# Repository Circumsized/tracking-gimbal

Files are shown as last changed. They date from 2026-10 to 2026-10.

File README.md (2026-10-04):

# 基于树莓派 Zero 2 W 的双轴微型视觉跟踪与测距云台系统









---

## 目录 (Table of Contents)

- [1. 系统全景与工程架构](#1-系统全景与工程架构)
  - [1.1 总体架构与数据流拓扑图 (SVG 矢量全景)](#11-总体架构与数据流拓扑图-svg-矢量全景)
  - [1.2 云台机械结构正交布局与 CAD 装配体系 (SVG 矢量图)](#12-云台机械结构正交布局与-cad-装配体系-svg-矢量图)
  - [1.3 系统物理拓扑与电气互联网络 (Mermaid)](#13-系统物理拓扑与电气互联网络-mermaid)
  - [1.4 树莓派 40-Pin GPIO 物理引脚工程映射 (ASCII)](#14-树莓派-40-pin-gpio-物理引脚工程映射-ascii)
  - [1.5 系统核心工程参数规范表](#15-系统核心工程参数规范表)
  - [1.6 系统 8 维工程性能雷达对比评估](#16-系统-8-维工程性能雷达对比评估-svg-矢量图)
- [2. 硬件电路设计与真实工程 BOM](#2-硬件电路设计与真实工程-bom)
  - [2.1 专用底板原理图拓扑结构 (SVG 矢量图)](#21-专用底板原理图拓扑结构-svg-矢量图)
  - [2.2 供电电源树与地平面隔离](#22-供电电源树与地平面隔离)
  - [2.3 嘉立创专业版工程真实提取器件清单 (BOM)](#23-嘉立创专业版工程真实提取器件清单-bom)
  - [2.4 硬件电气极限参数规范表](#24-硬件电气极限参数规范表)
  - [2.5 SPI0 总线通信事务时序图 (ASCII Timing)](#25-spi0-总线通信事务时序图-ascii-timing)
- [3. 通信总线与底层协议全景解析](#3-通信总线与底层协议全景解析)
  - [3.1 CAN 2.0B 物理层时序与 GL40 报文全协议位域 (SVG 矢量图)](#31-can-20b-物理层时序与-gl40-报文全协议位域-svg-矢量图)
  - [3.2 二进制通信位域与数据帧布局全图 (SVG 矢量图)](#32-二进制通信位域与数据帧布局全图-svg-矢量图)
  - [3.3 CubeMars GL40 CAN 驱动总线规范 (11-bit 标准帧)](#33-cubemars-gl40-can-驱动总线规范-11-bit-标准帧)
    - [3.3.1 CAN 报文与 IEEE-754 寄存器位域深度映射 (ASCII)](#331-can-报文与-ieee-754-寄存器位域深度映射-ascii)
    - [3.3.2 GL40 电机驱动器反馈状态遥测帧位域解析 (ASCII)](#332-gl40-电机驱动器反馈状态遥测帧位域解析-ascii)
  - [3.4 北醒 TFmini Plus UART 测距协议](#34-北醒-tfmini-plus-uart-测距协议)
    - [3.4.1 TFmini 9 字节缓冲区内存布局 (ASCII)](#341-tfmini-9-字节缓冲区内存布局-ascii)
    - [3.4.2 串口流双字节滑动窗口同步有限状态机 (Mermaid FSM)](#342-串口流双字节滑动窗口同步有限状态机-mermaid-fsm)
- [4. 视觉感知与空间定位引擎](#4-视觉感知与空间定位引擎)
  - [4.1 针孔成像几何与激光测距同轴投影空间图 (SVG 矢量图)](#41-针孔成像几何与激光测距同轴投影空间图-svg-矢量图)
  - [4.2 树莓派 ISP 图像预处理与 YuNet 张量流水线 (Mermaid)](#42-树莓派-isp-图像预处理与-yunet-张量流水线-mermaid)
  - [4.3 像平面视场几何、极性与死区盒空间分布 (ASCII)](#43-像平面视场几何极性与死区盒空间分布-ascii)
  - [4.4 视场像平面速度矢量分布与热力云图](#44-视场像平面速度矢量分布与热力云图)
  - [4.5 运动学连杆与 DH 坐标变换树 (Kinematic Tree)](#45-运动学连杆与-dh-坐标变换树-kinematic-tree)
- [5. 双轴闭环控制律推导与相平面动力学](#5-双轴闭环控制律推导与相平面动力学)
  - [5.1 经典控制工程离散闭环控制方块图 (SVG 矢量图)](#51-经典控制工程离散闭环控制方块图-svg-矢量图)
  - [5.2 比例速度控制数学建模与参数矩阵](#52-比例速度控制数学建模与参数矩阵)
  - [5.3 控制律非线性物理特性解析 (死区跳变与限幅失效)](#53-控制律非线性物理特性解析-死区跳变与限幅失效)
  - [5.4 像平面 2D 状态相空间收敛流线场 (Phase Portrait)](#54-像平面-2d-状态相空间收敛流线场-phase-portrait)
  - [5.5 阶跃响应与突变扰动抗扰仿真](#55-阶跃响应与突变扰动抗扰仿真)
- [6. 软件工程架构与时间预算管理](#6-软件工程架构与时间预算管理)
  - [6.1 模块类关系拓扑图 (Class Diagram)](#61-模块类关系拓扑图-class-diagram)
  - [6.2 跨模块数据实体模型图 (Data Entity Model)](#62-跨模块数据实体模型图-data-entity-model)
  - [6.3 系统全生命周期与电机运行状态机 (State Machine)](#63-系统全生命周期与电机运行状态机-state-machine)
  - [6.4 单周期流水线时延与四核并发架构 (纯矢量图 + 架构图)](#64-单周期流水线时延与四核并发架构-纯矢量图--架构图)
  - [6.5 线程间数据共享与互斥锁临界区拓扑 (ASCII)](#65-线程间数据共享与互斥锁临界区拓扑-ascii)
  - [6.6 远程 Web 推流网络会话生命周期时序图 (Mermaid Sequence)](#66-远程-web-推流网络会话生命周期时序图-mermaid-sequence)
  - [6.7 开机自检 (POST) 与异常故障隔离决策树 (Fault Tree)](#67-开机自检-post-与异常故障隔离决策树-fault-tree)
- [7. 源码缺陷严谨审计与修复补丁 (Bug Audit)](#7-源码缺陷严谨审计与修复补丁-bug-audit)
  - [7.1 源码缺陷审计表 (含 CVSS 评级)](#71-源码缺陷审计表-含-cvss-评级)
  - [7.2 工程级热修复补丁代码](#72-工程级热修复补丁代码)
- [8. 系统部署、环境搭建与运行指南](#8-系统部署环境搭建与运行指南)
  - [8.1 树莓派底层总线配置 (`/boot/config.txt`)](#81-树莓派底层总线配置-bootconfigtxt)
  - [8.2 SocketCAN 网络初始化与诊断](#82-socketcan-网络初始化与诊断)
  - [8.3 软件依赖安装与服务自启托管](#83-软件依赖安装与服务自启托管)
- [9. 工程排障与维护对照手册](#9-工程排障与维护对照手册)
- [10. 工程全量资料索引](#10-工程全量资料索引)
  - [10.1 专项工程技术规范文档矩阵 (Specialized Technical Specs)](#101-专项工程技术规范文档矩阵-specialized-technical-specs)
  - [10.2 全工程代码与多媒体资产树](#102-全工程代码与多媒体资产树)

---

## 1. 系统全景与工程架构

本项目面向超小型无人平台、移动侦察机器人及室内智能安防场景，构建了一套软硬件深度协同的轻量级微型双轴（水平偏航 Yaw / 垂直俯仰 Pitch）自动视觉跟踪与激光测距云台系统。

计算核心基于低功耗嵌入式单板计算机 **树莓派 Zero 2 W**（Broadcom BCM2710A1 四核 64 位 Cortex-A53 架构，主频 1.0GHz），感知层采用索尼 **IMX219 广角 CSI 摄像头**（130° 视角）并联北醒 **TFmini Plus 飞行时间 (ToF) 激光测距传感器**，动力执行单元选用两台 **CubeMars GL40 FOC 无刷直驱云台模组**。系统以硬实时 **50Hz (20ms)** 为主闭环周期，在极度受限的边缘算力下实现无超调、抗高频微颤的平滑跟踪。

### 1.1 总体架构与数据流拓扑图 (SVG 矢量全景)

系统端到端数据流拓扑如下图所示。全链路串联了图像采集、YuNet 人脸推理、偏差解算、SocketCAN 电机控制与局域网 Web 视频推流：

微型双轴视觉跟踪与测距云台系统架构图

---

### 1.2 云台机械结构正交布局与 CAD 装配体系 (SVG 矢量图)

系统机械结构基于 SolidWorks 完整建模。Yaw 轴采用微型导电滑环实现 $360^\circ$ 无限位旋转，Pitch 轴采用直驱侧装支撑铝合金 U 型臂，传感器载荷质心严格配置在俯仰回转轴线上：

双轴跟踪云台机械结构正交轴系布局与载荷空间拓扑

---

### 1.3 系统物理拓扑与电气互联网络 (Mermaid)

```mermaid
flowchart TD
    subgraph POWER_DOMAIN["供电与动力母线"]
        XT30["XT30 动力接口<br/>12V ~ 24V DC 主供电"]
    end

    subgraph PCB_CARRIER["专用转接底板工程 ProPrj_跟踪云台电路板.epro2"]
        LM2596["LM2596S-5.0<br/>开关稳压芯片 5V/3A"]
        MCP2515["MCP2515T-I/ST<br/>SPI-CAN 控制器 (TSSOP-20)"]
        OSC["SMD3225 晶振<br/>8.000MHz（实测待确认，见 HARDWARE_DESIGN DEV-HW-01）"]
        CAN_PHY1["SN65HVD230DR<br/>3.3V CAN 收发器 1"]
        CAN_PHY2["SN65HVD231DR<br/>3.3V CAN 收发器 2"]
    end

    subgraph CONTROLLER_MODULE["计算核心: 树莓派 Zero 2 W"]
        CPU["4× Cortex-A53 @ 1.0GHz / 512MB LPDDR2"]
        CSI_IF["MIPI CSI-2 2-Lane 接口"]
        SPI_IF["硬件 SPI0: SCLK / MOSI / MISO / CE0"]
        UART_IF["硬件串口 PL011: /dev/serial0"]
        GPIO25["GPIO25: MCP2515 外部硬件中断"]
        WIFI_NET["板载 2.4GHz Wi-Fi / Web 推流"]
    end

    subgraph PERCEPTION_DOMAIN["多模态感知单元"]
        CAM["IMX219 广角摄像头<br/>1640x1232 硬件捕获"]
        LIDAR["TFmini Plus 激光雷达<br/>UART 115,200 bps @ 100Hz"]
    end

    subgraph ACTUATION_DOMAIN["动力执行单元: CubeMars GL40 直驱模组"]
        MOTOR_YAW["Yaw 航向轴电机<br/>Node ID: 0x201 (速度模式 2)"]
        MOTOR_PITCH["Pitch 俯仰轴电机<br/>Node ID: 0x202 (速度模式 2)"]
    end

    XT30 -->|"12V~24V 动力直供"| LM2596
    XT30 -->|"24V 动力高压总线"| MOTOR_YAW
    XT30 -->|"24V 动力高压总线"| MOTOR_PITCH
    LM2596 -->|"VCC 5V 稳压输出"| CONTROLLER_MODULE

    CAM -->|"CSI-2 差分图像流"| CSI_IF
    LIDAR -->|"TTL 串口 TX/RX"| UART_IF

    SPI_IF <-->|"SPI 通信 (Mode 0,0)"| MCP2515
    MCP2515 -->|"INT 低电平中断触发"| GPIO25
    OSC --- MCP2515

    MCP2515 <-->|"TTL Tx/Rx"| CAN_PHY1
    MCP2515 -.->|"备用通道"| CAN_PHY2
    CAN_PHY1 <-->|"CAN_H / CAN_L 差分对 (1Mbps)"| MOTOR_YAW
    CAN_PHY1 <-->|"CAN_H / CAN_L 差分对 (1Mbps)"| MOTOR_PITCH

    WIFI_NET -.->|"HTTP MJPEG 流 :5000"| CLIENT[局域网浏览器调试终端]
```

---

### 1.4 树莓派 40-Pin GPIO 物理引脚工程映射 (ASCII)

底板通过 2.54mm 双排母与树莓派 Zero 2 W 的 40-Pin GPIO 紧凑对接。下表展现了关键功能管脚的物理拓扑分配：

```
                              树莓派 Zero 2 W 40-Pin 排针
                               +-------------------+
             [3.3V 供电基准]   |  1 (3V3)   (5V) 2 |   <== [LM2596 5V 主供电输入]
                    (GPIO 2)   |  3 (SDA)   (5V) 4 |   <== [LM2596 5V 主供电输入]
                    (GPIO 3)   |  5 (SCL)   (GND) 6|   --- [系统总接地 GND]
                    (GPIO 4)   |  7 (GP4)  (TXD) 8 |   ==> [UART TX -> TFmini RX]
           [系统总接地 GND]    |  9 (GND)  (RXD) 10|   <== [UART RX <- TFmini TX]
                   (GPIO 17)   | 11 (GP17) (GP18) 12
                   (GPIO 27)   | 13 (GP27)  (GND) 14
                   (GPIO 22)   | 15 (GP22) (GP23) 16
                   (3.3V 预留) | 17 (3V3)  (GP24) 18
 [SPI0 MOSI -> MCP2515 SI]     | 19 (MOSI)  (GND) 20
 [SPI0 MISO <- MCP2515 SO]     | 21 (MISO) (GP25) 22|  <== [MCP2515 INT 中断输入]
 [SPI0 SCLK -> MCP2515 SCK]    | 23 (SCLK) (CE0)  24|  ==> [SPI0 CE0 -> MCP2515 CS]
                               | 25 (GND)  (CE1)  26
                               |  . . . . . . . .  |
                               +-------------------+
```

---

### 1.5 系统核心工程参数规范表

| 架构维度 | 关键参数项 | 真实源码 / 硬件定义 | 理论设计极限 | 实际工作区间与工程意义 |
| :--- | :--- | :--- | :--- | :--- |
| **主控芯片** | SoC 型号与核心 | Broadcom BCM2710A1 | 4 核 1.0GHz | 提供端侧边缘神经网络推理与 50Hz 控制闭环 |
| **内存规模** | 系统 RAM 规格 | 512MB LPDDR2 SDRAM | 共享显存 128MB | 内存占用控制：系统+模型+推流总驻留内存 < 180MB |
| **视觉采样** | 硬件原始传感器帧 | `capture_size = (1640, 1232)` | 传感器标称帧率上限（**本项目未实测，不作为验收判据**；实际帧率由下行 `FrameDurationLimits` 硬锁定） | 保持 IMX219 传感器 4:3 原生广角视场角，无裁切 |
| | 处理与推流帧 | `stream_size = (640, 480)` | 640×480 | 双线性下采样，兼顾人脸特征清晰度与毫秒级延迟 |
| | 帧间隔硬件限制 | `(20000, 20000) µs` | 50.0 FPS | `FrameDurationLimits` 强制硬件以 50Hz 等间隔曝光出帧 |
| **视觉算法** | 人脸检测模型 | OpenCV YuNet (2023mar ONNX) | 5000 候选框 | `score=0.6, nms=0.3`，单帧推理约 11.8ms |
| **激光测距** | 传感器型号及总线 | TFmini Plus, `/dev/serial0` | 100Hz 输出 | 115,200 bps，有效测距 $0.1\text{m} \sim 12\text{m}$，盲区 10cm |
| | 杂波与无效过滤 | `strength>100 && !=65535 && dist!=0` | 9 字节包格式 | 滤除低反射噪点、光学接收饱和以及超量程零点 |
| **执行机构** | 电机型号及拓扑 | CubeMars GL40 FOC 无刷模组 | 额定 24V / 2A | 直驱结构，无齿轮间隙，定位精度 0.1° |
| | CAN 总线协议规范 | 11-bit 标准帧，波特率 1Mbps | 8 字节负载 | 模式 2 速度控制，小端 float32 速度指令 (rad/s) |
| **闭环控制** | 控制周期及死区 | $T=20\text{ms}$ (50Hz), $\text{Deadzone}=15\text{px}$| 零延迟响应 | $\pm 15\text{px}$ 中心死区盒，消除视轴中心静止时的抖动 |
| | 轴向比例增益 | $K_{yaw}=0.003, K_{pitch}=0.003$ | $\text{rad/s}/\text{px}$ | 视场边界最大速度输出限制为 $0.96\text{ rad/s}$ |
| **网络流媒体**| 协议及服务端口 | Flask HTTP Multipart MJPEG | 端口 `5000` | JPEG 质量 80，流内部 30ms 节流 (~33.3 FPS) |

---

### 1.6 系统 8 维工程性能雷达对比评估 (SVG 矢量图)

针对云台在边缘算力平台上的综合表现，从闭环实时性、算力轻量度、无超调跟踪、死区抗微颤、测距同步率、CAN 总线抗扰、机械谐振刚度及能耗温升 8 个工程维度，对理论设计目标与实测硬件在环表现进行纯矢量高精对比如下：

系统8维工程性能雷达对比评估

---

## 2. 硬件电路设计与真实工程 BOM

### 2.1 专用底板原理图拓扑结构 (SVG 矢量图)

电路底板完整实现了高压动力直通母线、开关稳压输出、SPI 转 CAN 控制器与差分物理总线电平驱动：

硬件电路底板原理图拓扑结构

---

### 2.2 供电电源树与地平面隔离

1. **主电源注入级 (`VIN`)**：通过高可靠性 `XT30PW-M` 卧式大电流插头引入外部 12V ~ 24V 电池或稳压母线，一路直接为两台 GL40 无刷电机供电，另一路供给板载降压芯片。
2. **开关降压回路 (`5V`)**：采用 `LM2596SX-5.0/NOPB`（TO-263-5 表面贴装）组成降压转换电路，将高压转为纹波平稳的 5V/3A 电源，通过 40-Pin 双排插座引脚为树莓派主板及摄像头模组供电。
3. **数字与模拟分区隔离**：在 PCB Layout 中将电机侧高频开关大电流回路与敏感的 SPI/UART 数字走线分区走线，原理图严格区分 `GND` 与 `AGND`，在单点通过 $0\Omega$ 跳线贴片电阻实现共地抑制高频回流噪声。

---

### 2.3 嘉立创专业版工程真实提取器件清单 (BOM)

> [!NOTE]
> 下表为底板实际装配物料清单 (BOM)，提取自嘉立创专业版工程源文件 (`ProPrj_跟踪云台电路板.epro2`)。总线 120Ω 终端电阻位于外部总线线缆两端，底板不设板载终端。

| 标号 (Designator) | 元件型号 / 规格值 | 封装形式 (Package) | 数量 | 功能定义与连接网络说明 |
| :--- | :--- | :--- | :---: | :--- |
| **U1** | `LM2596SX-5.0/NOPB` | TO-263-5 (贴片) | 1 | 5V/3A DC-DC 开关降压稳压器，输入 `VIN`，输出 `VCC (5V)` |
| **U2** | `MCP2515T-I/ST` | TSSOP-20 (0.65mm) | 1 | 独立 SPI-CAN 控制器，连接树莓派 SPI 总线与 INT 中断线 |
| **U3** | `SN65HVD230DR` | SOIC-8 (150mil) | 1 | 3.3V CAN 差分总线收发器（兼容 PCA82C250，驱动 CANH/CANL） |
| **U4** | `SN65HVD231DR` | SOIC-8 (150mil) | 1 | 具备睡眠模式的超低功耗 3.3V CAN 收发器（备用节点接口） |
| **X1** | `X32258MSB4SI` | SMD3225-4P | 1 | 8.000MHz 无源晶振，为 MCP2515 提供精确的振荡时钟基准 |
| **C1, C2** | `CL10C100JB8NNNC` (10pF/50V) | 0603 贴片 | 2 | 晶振两端匹配负载电容，接晶振管脚与 `AGND` |
| **C3, C4** | `CGA0805X5R106K500MT` (10µF/50V) | 0805 贴片 | 2 | 芯片电源引脚高频滤波与退耦低 ESR 陶瓷电容 |
| **R1, R2** | `FRC0603J103TS` (10kΩ ±5%) | 0603 贴片 | 2 | 芯片复位管脚上拉电阻、中断管脚开漏上拉电阻 |
| **R3, R4** | `RC0603FR-070RL` (0Ω 跨接) | 0603 贴片 | 2 | 跳线/选焊零欧姆电阻，用于地线分区单点汇流与模式选择 |
| **CN1** | `XT30PW-M` | 卧式直插焊接 | 1 | 外部动力电源主输入公头连接器 |
| **CN2** | `GH1.25-6PWT` / `HC-1.25-2PWT` | GH 1.25mm 间距 | 多组 | 激光雷达 UART 信号接口及电机 CAN 信号接插座 |
| **J1** | `2.54mm 2x20 Pin Header` | 双排母插座 (40P) | 1 | 直接插接树莓派 Zero 2 W 的 40-Pin GPIO 扩展公针 |

---

### 2.4 硬件电气极限参数规范表

| 参数项 (Parameter) | 符号 | 最小值 (Min) | 典型值 (Typ) | 最大值 (Max) | 单位 | 备注 |
| :--- | :---: | :---: | :---: | :---: | :---: | :--- |
| **主供电输入电压** | $V_{IN}$ | 8.0 | 24.0 | 32.0 | V | 满足 GL40 电机驱动器工作范围 |
| **降压模块输出电压** | $V_{CC}$ | 4.85 | 5.05 | 5.25 | V | 树莓派及外设供电母线 |
| **静态待机电流** | $I_{standby}$ | 180 | 240 | 320 | mA | 树莓派+传感器在空闲状态 |
| **单轴电机扭矩量程** | $\tau_{range}$ | -10 | — | 10 | $\text{N}\cdot\text{m}$ | 手册 §5.4：控制/反馈 12-bit 映射 ±10 N·m；峰值扭矩手册未定义，以官方手册为准 |
| **CAN 总线终端电阻** | $R_{term}$ | — | 120 | — | $\Omega$ | 位于双绞线两端各一颗 |
| **工作环境温度** | $T_A$ | -10 | 25 | 60 | ℃ | 树莓派需配备被动散热片 |

---

### 2.5 SPI0 总线通信事务时序图 (ASCII Timing)

树莓派与 MCP2515 之间通过标准 SPI 模式 (Mode 0,0) 进行寄存器读写与 CAN 报文收发：

```
SPI Mode 0,0 读写事务与 MCP2515 硬件中断触发时序:
            __                                                                    __
/CS (CE0)     \__________________________________________________________________/
                 _   _   _   _   _   _   _   _   _   _   _   _   _   _   _   _
SCLK        ____/ \_/ \_/ \_/ \_/ \_/ \_/ \_/ \_/ \_/ \_/ \_/ \_/ \_/ \_/ \_/ \_
            ____   ___________________________   ___________________________   _____
MOSI (SI)   ____X_<______ 命令字节 (如 0x02) _>_X_<______ 寄存器地址 (0x31) _>_X_____
            __________________________________   ___________________________   _____
MISO (SO)   XXXXXXXXXXXXXXXXXXXXXXXXXXXXXXXXXX\_X_<______ 读取数据字节 (0xAA) _>_X_____
            ______________________________________                               ___
/INT (GPIO25)                                     \_____________________________/
                                                   ^ CAN 帧成功接收，触发低电平中断
```

---

## 3. 通信总线与底层协议全景解析

### 3.1 CAN 2.0B 物理层时序与 GL40 报文全协议位域 (SVG 矢量图)

下图详细拆解了 CAN 2.0B 标准数据帧的 SOF、11 位仲裁段、控制位、DLC、64 位数据负载段、CRC15 校验与从机 ACK 应答槽的时序参数与位域定义：

CAN 2.0B 物理层时序与 GL40 报文全协议位域

---

### 3.2 二进制通信位域与数据帧布局全图 (SVG 矢量图)

下图展示了系统两大通信协议的二进制位域划分细节，包括 GL40 标准帧 11-bit 仲裁 ID、8 字节速度负载小端浮点数字段分布，以及 TFmini Plus 9 字节串口数据包结构：

通信协议二进制位域布局与数据帧格式

---

### 3.3 CubeMars GL40 CAN 驱动总线规范 (11-bit 标准帧)

GL40 模组驱动器采用固定 **1Mbps** 波特率的 **11 位标准数据帧 (Standard Frame)**。

#### 3.3.1 CAN 报文与 IEEE-754 寄存器位域深度映射 (ASCII)

```
========================================================================================================
1. 11-Bit 仲裁段 ID (Standard CAN ID):
   Bit:   [10]    [9]    [8]   |   [7]    [6]    [5]    [4]    [3]    [2]    [1]    [0]
        +----------------------+-------------------------------------------------------+
  Field |   控制模式 (Mode)    |                  电机物理节点 ID (Node ID)            |
        | 0x02: 速度模式       | 0x01: Yaw 航向轴 (0x201) / 0x02: Pitch 俯仰轴 (0x202) |
        +----------------------+-------------------------------------------------------+

2. 64-Bit 数据负载段 (DLC = 8 Bytes):
   +---------------------------------------+---------------------------------------+
   |  Bytes 0 ~ 3: IEEE-754 速度 (rad/s)   |  Bytes 4 ~ 7: 系统保留填充 (0x00*4)   |
   +---------------------------------------+---------------------------------------+
   
   [Byte 0] Bits[7:0]   : Mantissa 尾数低 8 位 M[7:0]
   [Byte 1] Bits[15:8]  : Mantissa 尾数中 8 位 M[15:8]
   [Byte 2] Bits[23:16] : E[0] 阶码最低位 + M[22:16] 尾数高 7 位
   [Byte 3] Bits[31:24] : S[31] 符号位 (0正/1负) + E[30:24] 阶码高 7 位
   [Byte 4] 0x00 保留填充
   [Byte 5] 0x00 保留填充
   [Byte 6] 0x00 保留填充
   [Byte 7] 0x00 保留填充
========================================================================================================
```

#### 3.3.2 GL40 电机驱动器反馈状态遥测帧位域解析 (ASCII)

当主机读取驱动器反馈时（回传至 Master ID 0x000），8 字节遥测数据定义如下：

```
GL40 驱动器 8 字节反馈遥测帧 (Feedback Packet):
+----------+----------+----------+----------+----------+----------+----------+----------+
|  Byte 0  |  Byte 1  |  Byte 2  |  Byte 3  |  Byte 4  |  Byte 5  |  Byte 6  |  Byte 7  |
+----------+----------+----------+----------+----------+----------+----------+----------+
| ERR | ID | Position (16-bit)   | Velocity (12-bit)  | Torque (12-bit)   | T_driver | T_motor  |
+----------+---------------------+--------------------+-------------------+----------+----------+
  \    /
 [7:4] 故障码 ERR:
       0x0: 正常无故障失能态      0x1: 正常使能态          0x8: 总线超压 (Over-Voltage)
       0x9: 总线欠压             0xA: 相线过流 (OCP)      0xB: MOS 管过温 (>100℃)
       0xC: 线圈过温 (>120℃)     0xD: CAN 帧通讯丢失      0xE: 驱动器过载堵转
```

---

### 3.4 北醒 TFmini Plus UART 测距协议

测距模块通过串口 `/dev/serial0` 传输标准 9 字节定长二进制数据包，波特率为 **115,200 bps (8N1)**。

#### 3.4.1 TFmini 9 字节缓冲区内存布局 (ASCII)

```
TFmini Plus 9-Byte 串行数据帧内存映射:
+--------+--------+--------+--------+--------+--------+--------+--------+--------+
| Byte 0 | Byte 1 | Byte 2 | Byte 3 | Byte 4 | Byte 5 | Byte 6 | Byte 7 | Byte 8 |
+--------+--------+--------+--------+--------+--------+--------+--------+--------+
|  0x59  |  0x59  | Dist_L | Dist_H | Str_L  | Str_H  | Temp_L | Temp_H | Check  |
+--------+--------+--------+--------+--------+--------+--------+--------+--------+
|<-- 帧头同步 -->|<-- 距离 (cm) ->|<-- 信号强度 ->|<-- 内部温度 ->|<- 校验和 ->|
                  Distance =               Strength =
                  Dist_L + (Dist_H<<8)     Str_L + (Str_H<<8)
```

#### 3.4.2 串口流双字节滑动窗口同步有限状态机 (Mermaid FSM)

源码在 `tfmini_uart.py` 中实现了基于双字节滑动窗口的健壮流同步与 3 重条件物理门限过滤逻辑：

```mermaid
flowchart TD
    S0([WAIT_HEADER_1]) -->|"读取 1 字节"| C1{"字节 == 0x59 ?"}
    C1 -->|"否"| S0
    C1 -- 是 --> S1([WAIT_HEADER_2])

    S1 -->|"读取 1 字节"| C2{"字节 == 0x59 ?"}
    C2 -->|"否"| S0
    C2 -- 是 --> S2([READ_PAYLOAD_7B])

    S2 -->|"读取后 7 字节"| C3{"总长度 == 9 字节 ?"}
    C3 -->|"否"| S0
    C3 -- 是 --> S3([CHECKSUM_VALIDATE])

    S3 --> C4{"sum(Byte 0~7) & 0xFF == Byte 8 ?"}
    C4 -->|"否 (校验和错误)"| S0
    C4 -- 是 (校验通过) --> S4([PHYSICAL_FILTER])

    S4 --> C5{"strength > 100 且<br/>strength != 65535 且<br/>distance != 0 ?"}
    C5 -->|"否 (杂波/饱和/盲区)"| S0
    C5 -- 是 (物理数据有效) --> S5([UPDATE_SHARED_MEMORY])
    S5 -->|"进入临界区写入 distance"| S0
```

---

## 4. 视觉感知与空间定位引擎

### 4.1 针孔成像几何与激光测距同轴投影空间图 (SVG 矢量图)

下图直观阐明了摄像头光心 $O_c$、焦距 $f$、归一化像平面、目标三维空间点 $P(X,Y,Z)$ 与激光雷达测距光束的几何对齐关系：

针孔成像几何模型与空间同轴测距空间投影

---

### 4.2 树莓派 ISP 图像预处理与 YuNet 张量流水线 (Mermaid)

从物理 CMOS 靶面曝光到最终检出人脸边界框的端到端图像张量管线如下：

```mermaid
flowchart LR
    subgraph CMOS_HW["IMX219 传感器硬件"]
        RAW_CFA["原生 Bayer CFA 阵列<br/>1640×1232 原始数据"]
    end

    subgraph RPI_ISP["树莓派片上硬件 ISP 处理引擎"]
        BLC["黑电平校准 BLC"]
        LSC["镜头阴影衰减补偿 LSC"]
        DEMOSAIC["去马赛克插值 Demosaic"]
        AWB_AE["硬件 3A 闭环 AWB + AE"]
        FMT_OUT["RGB888 格式输出"]
    end

    subgraph SW_PIPELINE["Python 端处理流水线"]
        RESIZE["cv2.resize 缩放<br/>双线性插值 ➔ 640×480"]
        COLOR_FIX["cv2.cvtColor<br/>RGB ➔ BGR 色域对齐<br/>⚠ 当前被注释 (BUG-03)"]
        YUNET_INF["FaceDetectorYN 推理<br/>输入 [1, 3, 480, 640] 张量"]
        NMS_FILTER["置信度 > 0.6<br/>NMS > 0.3 抑制"]
        TARGET_PICK["选定最大面积目标<br/>max(w × h)"]
    end

    RAW_CFA --> BLC --> LSC --> DEMOSAIC --> AWB_AE --> FMT_OUT
    FMT_OUT --> RESIZE --> COLOR_FIX --> YUNET_INF --> NMS_FILTER --> TARGET_PICK
```

---

### 4.3 像平面视场几何、极性与死区盒空间分布 (ASCII)

```
(0,0) 原点                                                   (640,0)
  +-------------------------------------------------------------+
  |                                                             |
  |             ^ -Y (Pitch 电机上仰，PITCH_DIRECTION = +1)     |
  |             |                                               |
  |             |                                               |
  |             |       死区边界 Y = 240 ± 15                   |
  |             |       +-------------+                         |
  |    <--------+-------|  死区核心盒 |-------+-------->        |
  | -X (Yaw 左偏)       |  (速度 = 0) |       |  +X (Yaw 右偏)  |
  |                     +-------------+                         |
  |                     死区边界 X = 320 ± 15                   |
  |             |                                               |
  |             |                                               |
  |             v +Y (Pitch 电机下俯)                           |
  |                                                             |
  +-------------------------------------------------------------+
(0,480)                                                       (640,480)
基准中心: (cx0, cy0) = (320, 240)
有效跟踪视场: 640×480 px, 对角视场角 FOV ≈ 130°
```

---

### 4.4 视场像平面速度矢量分布与热力云图

下图清晰呈现了目标在视场不同区域引起的合成输出角速度模长等高线热力图：

视场平面目标分布与驱动速度模长热力拓扑

---

### 4.5 运动学连杆与 DH 坐标变换树 (Kinematic Tree)

系统各物理连杆及传感器坐标系之间的正向运动学变换关系如下：

```mermaid
flowchart TD
    W_FRAME["世界大地参考系 {W}"] -->|"T_base^world 刚性固定"| B_FRAME["云台基座固定参考系 {B}"]
    B_FRAME -->|"R_z(θ_yaw) 偏航电机转动"| Y_FRAME["Yaw 连杆参考系 {Y}"]
    Y_FRAME -->|"R_x(θ_pitch) 俯仰电机转动"| P_FRAME["Pitch 载荷平台参考系 {P}"]
    
    P_FRAME -->|"T_cam^pitch (安装平移与光轴基准)"| C_FRAME["IMX219 相机光心坐标系 {C}"]
    P_FRAME -->|"T_lidar^pitch (垂直基线偏置 dy=28mm)"| L_FRAME["TFmini 激光出射参考系 {L}"]
    
    C_FRAME -->|针孔透视投影矩阵 K| IMG_PLANE["二维像素图像平面 (u, v)"]
```

---

## 5. 双轴闭环控制律推导与相平面动力学

### 5.1 经典控制工程离散闭环控制方块图 (SVG 矢量图)

下图给出了严格符合经典现代控制理论规范的离散时间闭环控制方块图，包含目标输入、非线性死区截断环节、比例增益矩阵、零阶保持器、FOC 电机被控对象以及透视投影反馈通道：

跟踪云台双轴控制理论闭环控制框图

---

### 5.2 比例速度控制数学建模与参数矩阵

水平与垂直方向像素位置偏差定义：

$$
e_x = cx - 320, \qquad e_y = cy - 240
$$

带死区的比例截断速度控制律分段函数：

$$
v(e) = \begin{cases} 
0.0, & |e| \le \text{Deadzone} \\ 
\text{clamp}(|e| \cdot K_p, \, v_{\min}, \, v_{\max}) \cdot \text{sgn}(e) \cdot \text{Direction}, & |e| > \text{Deadzone} 
\end{cases}
$$

式中参数说明：
- $e$：目标特征点相对画面中心的像素位置偏差（单位：$\text{px}$）；
- $\text{Deadzone}$：抗机械微颤死区半宽阈值（水平与垂直轴向均设为 $15\,\text{px}$）；
- $K_p$：比例速度增益系数（设定为 $0.003\,\text{rad/s/px}$）；
- $v_{\min}, v_{\max}$：算法理论速度限幅区间（设定为 $[0.02, 100.0]\,\text{rad/s}$）；
- $\text{Direction}$：轴向运动极性修正因子（偏航轴为 $-1$，俯仰轴为 $+1$）。

| 轴向控制变量 | 比例增益 $K_p$ | 死区阈值 $\text{Deadzone}$ | 理论限幅区间 $[v_{min}, v_{max}]$ | 方向极性 $\text{Direction}$ | 实际工作输出极值 |
| :---: | :---: | :---: | :---: | :---: | :---: |
| **Yaw 航向轴** | `0.003` rad/s/px | `15` px | `[0.02, 100.0]` rad/s | `-1` (反向补偿像移) | $\pm [0.048, 0.96]\text{ rad/s}$ |
| **Pitch 俯仰轴**| `0.003` rad/s/px | `15` px | `[0.02, 100.0]` rad/s | `+1` (同向补偿像移) | $\pm [0.048, 0.72]\text{ rad/s}$ |

---

### 5.3 控制律非线性物理特性解析 (死区跳变与限幅失效)

比例速度控制律精细特性与截断分析

1. **死区边界非连续速度起跳**：

$$
v_{start} = 16 \times 0.003 = 0.048 \text{ rad/s} \approx 2.75^\circ/\text{s}
$$

2. **理论最小速度限幅 ($v_{min} = 0.02$) 成为死代码 (Dead Code)**：
   由于起步速度 $0.048\text{ rad/s} > 0.02\text{ rad/s}$，所有死区外的计算值天然高于 $v_{min}$，`clamp` 函数中的下限保护永远不会被触发。
3. **理论上限 ($v_{max} = 100.0$) 永不饱和**：
   画面视场物理边界最大偏差 $e_{x\_max} = 320\text{px}$，最大输出速度为 $320 \times 0.003 = 0.96\text{ rad/s}$，远未触及 $100.0\text{ rad/s}$。

---

### 5.4 像平面 2D 状态相空间收敛流线场 (Phase Portrait)

双轴状态空间的收敛行为可以通过 2D 相平面（水平偏差 $e_x$ vs 垂直偏差 $e_y$）流线场直观表征：

像平面二维误差相空间收敛流线场与典型轨迹

---

### 5.5 阶跃响应与突变扰动抗扰仿真

下图模拟了目标发生 220px 阶跃偏差并在中途注入 80px 突变扰动工况下，带死区控制系统与无死区控制系统的收敛动态响应对比：

闭环控制系统抗扰动动态阶跃响应对比仿真

---

## 6. 软件工程架构与时间预算管理

### 6.1 模块类关系拓扑图 (Class Diagram)

```mermaid
classDiagram
    class YuNetCamera {
        +tuple capture_size = (1640, 1232)
        +tuple stream_size = (640, 480)
        +Picamera2 picam2
        +FaceDetectorYN detector
        +read() ndarray
        +detect_faces(frame) tuple
        +detect_largest_face(frame) dict
        note for YuNetCamera "detect_largest_face 为 BUG-01/02 修复补丁新增<br/>当前源码基线中不存在（见 §7.1）"
    }

    class TFminiReader {
        +str port = "/dev/serial0"
        +int baudrate = 115200
        +int distance
        +int strength
        +bool running
        -threading.Lock lock
        -_read_frame(ser) tuple
        -_loop() void
        +start() void
        +get_distance() int
        +stop() void
    }

    class GimbalCAN {
        +can.interface.Bus bus
        +int yaw_id = 0x201
        +int pitch_id = 0x202
        +bytes enable_cmd
        +bytes disable_cmd
        +send(can_id, data) void
        +enable() void
        +disable() void
        +pack_speed(vel) bytes
        +send_speed(yaw_vel, pitch_vel) void
        +stop() void
        +close() void
    }

    class MJPEGStreamer {
        +Flask app
        +str host = "0.0.0.0"
        +int port = 5000
        +ndarray frame
        -threading.Lock lock
        +update_frame(frame) void
        +generate() bytes
        +video() Response
        +start() void
    }

    class MainLoop {
        +float CONTROL_PERIOD = 0.02
        +int DEADZONE_X = 15
        +int DEADZONE_Y = 15
        +float YAW_GAIN = 0.003
        +calc_speed(err, gain, min, max, dz, dir) float
        +draw_overlay(frame, face, dist) ndarray
        +main() void
    }

    MainLoop *-- YuNetCamera : 视觉帧捕获与模型推理
    MainLoop *-- TFminiReader : 异步串口雷达数据采样
    MainLoop *-- GimbalCAN : SocketCAN 双电机总线下发
    MainLoop *-- MJPEGStreamer : 局域网 HTTP 视频推流
```

---

### 6.2 跨模块数据实体模型图 (Data Entity Model)

```mermaid
classDiagram
    class DetectedFaceEntity {
        +int x
        +int y
        +int w
        +int h
        +int cx
        +int cy
        +int area
        +int count
        note for DetectedFaceEntity "count 为 BUG-02 修复补丁注入字段<br/>当前源码基线中不存在（见 §7.1/§7.2）"
    }

    class LidarSampleEntity {
        +int distance_cm
        +int signal_strength
        +bool is_valid
        +float timestamp
    }

    class MotorSpeedCommand {
        +int can_id
        +float vel_rad_s
        +bytes payload_8b
        +bool is_extended = False
    }

    class OSDDisplayFrame {
        +ndarray raw_bgr_image
        +tuple crosshair_pos = (320, 240)
        +tuple crosshair_color
        +str distance_osd_text
    }

    DetectedFaceEntity ..> MotorSpeedCommand : 计算误差驱动速度
    DetectedFaceEntity ..> OSDDisplayFrame : 叠加跟踪边界框
    LidarSampleEntity ..> OSDDisplayFrame : 叠加测距毫米波文本
```

---

### 6.3 系统全生命周期与电机运行状态机 (State Machine)

```mermaid
stateDiagram-v2
    [*] --> POWER_ON : 系统上电启动 (24V 母线注入)
    
    state POWER_ON {
        [*] --> HARDWARE_PROBE
        HARDWARE_PROBE --> SPI_CAN_INIT : MCP2515 驱动挂载
        SPI_CAN_INIT --> UART_PROBE : /dev/serial0 建立波特率 115200
        UART_PROBE --> CAMERA_WARMUP : Picamera2 曝光稳定 (1秒延时)
    }

    POWER_ON --> MOTORS_ENABLING : 主控制进程进入 main()
    
    state MOTORS_ENABLING {
        [*] --> SEND_ENABLE_0x201 : 下发 Yaw 使能 (FF*7+FC)
        SEND_ENABLE_0x201 --> DELAY_20MS : 硬件睡眠 20ms
        DELAY_20MS --> SEND_ENABLE_0x202 : 下发 Pitch 使能 (FF*7+FC)
        SEND_ENABLE_0x202 --> MOTORS_STANDBY : 电机进入 FOC 闭环伺服状态
    }

    MOTORS_ENABLING --> CLOSED_LOOP_TRACKING : 50Hz 定时器启动

    state CLOSED_LOOP_TRACKING {
        [*] --> TARGET_SEARCHING : 遍历检测人脸
        TARGET_SEARCHING --> IN_DEADZONE : 目标人脸落入 ±15px 死区盒
        IN_DEADZONE --> SEND_BRAKE : 下发 0.0 rad/s 速度刹车
        
        TARGET_SEARCHING --> ACTIVE_TRACKING : 目标偏离死区 (|e| > 15px)
        ACTIVE_TRACKING --> SPEED_CONTROL : 计算 P 环速度并下发 0x201 & 0x202
        
        ACTIVE_TRACKING --> TARGET_LOST : 连续丢帧 / 遮挡
        TARGET_LOST --> SEND_BRAKE : 紧急刹车防止飞车
    }

    CLOSED_LOOP_TRACKING --> SAFE_SHUTDOWN : 捕获 SIGINT (Ctrl+C)
    
    state SAFE_SHUTDOWN {
        [*] --> MOTORS_STOP : 下发速度 0.0 rad/s 停转
        MOTORS_STOP --> DELAY_50MS : 延时 50ms 消除机械动能
        DELAY_50MS --> SEND_DISABLE_ALL : 下发失能指令 (FF*7+FD)
        SEND_DISABLE_ALL --> BUS_CLOSE : SocketCAN 关闭总线句柄
        BUS_CLOSE --> THREADS_TERMINATE : 停止雷达与推流后台守护线程
    }

    SAFE_SHUTDOWN --> [*] : 安全断电退出
```

---

### 6.4 单周期流水线时延与四核并发架构 (纯矢量图 + 架构图)

单帧端到端从感光采样到双轴电机响应的精确时间推进线如下图所示（标称门限 20ms 与实测单周期约 22.7ms 双基准）：

单周期端到端处理流水线时序图

树莓派 Zero 2 W 的四核 Cortex-A53 架构在单个主循环迭代（门限 20ms，实测约 22.6ms）内实现多任务并行调度拓扑如下：

```mermaid
flowchart TD
    subgraph CORE0["CPU Core 0: 主控制闭环 (50Hz 硬时钟驱动)"]
        direction TB
        C0_1["1. Picamera2 帧捕获与降采样 (4.2ms)"] --> C0_2["2. YuNet ONNX 人脸推理 (11.8ms)"]
        C0_2 --> C0_3["3. 偏差解算与 P 环速度计算 (0.8ms)"]
        C0_3 --> C0_4["4. CAN 双轴下发含 5ms 休眠 (5.3ms)"]
    end

    subgraph CORE1["CPU Core 1: 异步激光测距守护线程 (100Hz 独立流)"]
        direction TB
        C1_1["1. 阻塞读取 /dev/serial0 UART 缓冲区"] --> C1_2["2. 双 0x59 帧头同步与累加和校验"]
        C1_2 --> C1_3["3. 三重物理门限过滤 (强度/饱和/盲区)"]
        C1_3 --> C1_4["4. threading.Lock 保护写入共享距离值"]
    end

    subgraph CORE2["CPU Core 2/3: 局域网 Web 视频推流服务 (Flask 异步线程)"]
        direction TB
        C2_1["1. 从主循环安全拷贝最新渲染帧"] --> C2_2["2. JPEG 软件有损压缩编码 (质量 Q80)"]
        C2_2 --> C2_3["3. HTTP Multipart 协议持续推流响应"]
        C2_3 --> C2_4["4. 内部 30ms 节流休眠控制 (~33.3 FPS)"]
    end

    C1_4 -.->|"非阻塞持锁读取距离"| C0_3
    C0_4 -.->|"更新显示帧缓冲区"| C2_1

    classDef coreCls fill:#111827,stroke:#334155,stroke-width:1.5px,color:#f8fafc;
    class CORE0,CORE1,CORE2 coreCls;
```

> [!NOTE]
> **单周期时延口径说明**：`send_speed()` 内的 5ms 轴间休眠加上两帧发送开销合计约为 5.3ms，使得单次主循环迭代累计约为 22.6ms。因此门控 `if now - last_control_time >= CONTROL_PERIOD` 在每轮迭代均满足，**实际有效闭环控制率约为 44Hz ~ 45Hz**。该 5ms 延时有效防止了 SPI 发送邮箱拥堵与电机从机丢帧。详细的单周期时间预算分解见 `docs/CONTROL_AND_VISION.md` 第 6 章。

---

### 6.5 线程间数据共享与互斥锁临界区拓扑 (ASCII)

```
===================================================================================
多线程共享数据与互斥锁 (threading.Lock) 安全拓扑
===================================================================================

[TFmini 串口接收线程]                                [主控制 50Hz 闭环线程]
         |                                                     |
         v (产生有效距离)                                       v (主循环周期采样)
+-----------------------+                             +-----------------------+
| TFminiReader._loop()  |                             |      main.py:main()   |
|   ser.read(9) -> OK   |                             |   now - last >= 0.02  |
+-----------------------+                             +-----------------------+
         |                                                     |
         | Acquire Lock                                        | Acquire Lock
         v                                                     v
+=================================================================================+
|                       TFminiReader.lock 临界保护区                              |
|   self.distance = distance (cm)  <======>  distance = lidar.get_distance()      |
|   self.strength = strength                                                      |
+=================================================================================+
         | Release Lock                                        | Release Lock
         |                                                     v
         |                                            +-----------------------+
         |                                            | draw_overlay(frame)   |
         |                                            +-----------------------+
         |                                                     |
         |                                                     | Update Frame
         v                                                     v
[Web MJPEG 推流后台线程]                                       |
+-----------------------+                                      |
| MJPEGStreamer.generate|                                      |
|   read for JPEG encode|                                      |
+-----------------------+                                      |
         |                                                     |
         | Acquire Lock                                        | Acquire Lock
         v                                                     v
+=================================================================================+
|                     MJPEGStreamer.lock 临界保护区                               |
|   frame = self.frame.copy()      <======>   self.frame = frame.copy()           |
+=================================================================================+
         | Release Lock                                        | Release Lock
         v                                                     v
    cv2.imencode(.jpg)                                    推入下一周期循环
===================================================================================
```
> **读图说明（第 3 轮审查补充）**：上图中 TFmini 线程的 `ser.read(9)` 为**逻辑示意简写**，源码 `tfmini_uart.py::_read_frame()` 实际分三次读取（`ser.read(1)` ×2 取双帧头 `0x59 0x59`，再 `ser.read(7)` 读后续 7 字节，合计 1+1+7 = 9 字节），并依次经长度判定（`len(frame) != 9`）、累加校验和（`sum(frame[0:8]) & 0xFF`）与三重物理门限（`strength > 100`、`strength != 65535`、`distance != 0`）后才写入临界区。逐位行为见《PROTOCOL_SPEC》§4.3；该简写易使人误以为存在"单次 9 字节读调用"，调试时以源码为准。

```mermaid
sequenceDiagram
    autonumber
    actor Client as 远程监控客户端 (浏览器)
    participant Flask as Flask Server (mjpeg_stream.py)
    participant Gen as generate() 图像生成器
    participant Main as 主线程 (main.py)

    Client->>Flask: HTTP GET /
    Flask-->>Client: 200 OK (HTML 页面: <img src="/video">)

    Client->>Flask: HTTP GET /video
    Flask->>Gen: 启动生成器迭代器线程
    Flask-->>Client: 200 OK (Content-Type multipart/x-mixed-replace, boundary=frame)

    loop 每 30ms 节流轮询推送 (33.3 FPS)
        Main->>Flask: update_frame(display_frame) (写入新帧)
        Gen->>Flask: with lock: frame = self.frame.copy()
        Gen->>Gen: cv2.imencode('.jpg', frame, [QUALITY, 80])
        Gen-->>Client: 推送分帧 --frame (Content-Type image/jpeg, 载荷为 JPEG 二进制流)
        Note over Client: 浏览器原地平滑刷新单帧，无页面跳转
    end

    Client->>Flask: TCP FIN / RST (关闭网页)
    Flask->>Gen: GeneratorExit 异常退出
    Flask-->>Flask: 释放客户端线程连接资源
```

---

### 6.7 开机自检 (POST) 与异常故障隔离决策树 (Fault Tree)

```mermaid
flowchart TD
    BOOT([云台系统启动]) --> P1{检查模型文件存在 ?<br/>/home/jr/models/face_detection_yunet_2023mar.onnx}
    P1 -- 否 --> E1[抛出 FileNotFoundError<br/>停止运行并告警]
    P1 -- 是 --> P2{探测 CSI 摄像头硬件 ?<br/>Picamera2.start}

    P2 -- 失败 --> E2[摄像头硬件故障 / 排线未插牢<br/>系统紧急终止]
    P2 -- 成功 --> P3{初始化 SocketCAN can0 ?<br/>ip link show can0}

    P3 -- 未就绪 --> E3[MCP2515 驱动未加载<br/>进入视觉推流单机离线模式]
    P3 -- 就绪 --> P4{打开 /dev/serial0 串口 ?}

    P4 -- 失败 --> E4[TFmini 未接线或权限不足<br/>降级运行: 测距显示 -- cm]
    P4 -- 成功 --> P5[进入 50Hz 闭环工作模式]

    P5 --> RUN_LOOP{运行中异常监测}
    RUN_LOOP -- CAN 发送超时/溢出 --> F1[记录异常并复位 can0 缓冲区]
    RUN_LOOP -- 目标丢失 > 0.5s --> F2[电机强制下发 0.0 rad/s 锁死]
    RUN_LOOP -- 捕获 SIGINT (Ctrl+C) --> EXIT[优雅停机: 电机停转 -> 失能 -> 退出]
```

---

## 7. 源码缺陷严谨审计与修复补丁 (Bug Audit)

经对 `2、软件代码/project/` 下全部源码逐行静态审查，发现了 2 项直接导致程序首帧崩溃的 **致命 Bug (Critical)** 及 2 项影响画质与稳定性的缺陷：

### 7.1 源码缺陷审计表 (含 CVSS 评级)

| 缺陷 ID | 严重等级 (CVSS) | 触发文件与行号 | 缺陷触发根因 | 运行时崩溃现象与后果 |
| :---: | :---: | :--- | :--- | :--- |
| **BUG-01** | <font color=red>**CRITICAL (9.1)**</font> | `main.py:123` | `camera.detect_largest_face(frame)` 方法未定义！`YuNetCamera` 类中唯一定义的方法为 `detect_faces`。 | **首帧运行即崩**：抛出 `AttributeError: 'YuNetCamera' object has no attribute 'detect_largest_face'`。 |
| **BUG-02** | <font color=red>**CRITICAL (8.8)**</font> | `main.py:75` | `draw_overlay` 尝试访问 `face['count']`，但 `detect_faces` 返回的字典只有 `x, y, w, h, cx, cy, area`。 | **检出人脸即崩**：检测到目标首帧立即抛出 `KeyError: 'count'` 异常终止。 |
| **BUG-03** | <font color=orange>**MEDIUM (5.3)**</font> | `camera_yunet.py:50` | `frame = cv2.cvtColor(frame, cv2.COLOR_RGB2BGR)` 被意外注释。Picamera2 输出 RGB，而 OpenCV/YuNet 需 BGR。 | **检测率下降且场景偏色**：YuNet 输入通道 R/B 互换导致置信度漂移与漏检，Web 画面场景像素红蓝互换（OSD 叠加色绘制与编码同为 BGR 约定，不受影响）。 |
| **BUG-04** | <font color=blue>**LOW (3.1)**</font> | `gimbal_can.py:19` | 驱动完全开环发送，未配置接收缓冲区消费反馈帧、无总线脱机自动重连机制；`send(msg, timeout=0.05)` 已有 50ms 发送超时，但对超时/断链抛出的 `can.CanError` 无捕获保护。 | 总线脱线或发送超时时 `bus.send` 抛 `can.CanError` 无人捕获 → 主循环中断并经 `finally` 停机链退出（**非挂起**），跟踪功能丧失至 systemd 重启。 |

---

### 7.2 工程级热修复补丁代码

#### 1) 修复 `camera_yunet.py`

```python
# ==================== camera_yunet.py 修复补丁 ====================
def read(self):
    frame = self.picam2.capture_array()
    frame = cv2.resize(frame, self.stream_size)

    # [修复 BUG-03]: 恢复色彩转换，Picamera2 RGB 转换为 OpenCV 标准 BGR
    frame = cv2.cvtColor(frame, cv2.COLOR_RGB2BGR)
    return frame

def detect_largest_face(self, frame):
    """
    [修复 BUG-01 & BUG-02]: 补充与 main.py 匹配的接口，并注入 count 统计字段
    """
    results, selected_face = self.detect_faces(frame)
    if selected_face is not None:
        selected_face["count"] = len(results)  # 注入人脸总数，消除 KeyError
    return selected_face
```

#### 2) 修复 `main.py` 的异常防护

```python
# ======================== main.py 稳健性修补 ========================
# 替换 main() 中的目标捕获逻辑：
try:
    frame = camera.read()
    face = camera.detect_largest_face(frame)
except AttributeError:
    # 兼容未应用补丁的原生 camera_yunet.py
    faces_list, face = camera.detect_faces(frame)
    if face is not None:
        face["count"] = len(faces_list)
```

---

## 8. 系统部署、环境搭建与运行指南

### 8.1 树莓派底层总线配置 (`/boot/config.txt`)

登录树莓派终端，编辑底层设备树驱动加载项：

```ini
# 启用硬件 SPI0 接口 (用于 MCP2515 CAN 控制器)
dtparam=spi=on

# 加载 MCP2515 驱动 (设定外部晶振为 8MHz，中断信号脚接 GPIO25)
dtoverlay=mcp2515-can0,oscillator=8000000,interrupt=25
dtoverlay=spi-bcm2835

# 启用主硬件串口 /dev/serial0 并释放蓝牙占用
enable_uart=1
dtoverlay=disable-bt
```

---

### 8.2 SocketCAN 网络初始化与诊断

在 Linux 网络层将 `can0` 接口配置为 1Mbps：

```bash
# 1. 激活 can0 网卡并绑定 1000000 (1Mbps) 波特率
sudo ip link set can0 type can bitrate 1000000
sudo ip link set can0 up

# 2. 检查 CAN 总线运行状态与收发统计
ip -details link show can0

# 3. 监听总线原始数据流 (需安装 can-utils)
candump can0
```

---

### 8.3 软件依赖安装与服务自启托管

```bash
# 1. 更新系统包并安装核心运行环境
sudo apt update
sudo apt install -y python3-pip python3-opencv python3-picamera2 can-utils
pip3 install python-can flask pyserial --break-system-packages   # Bookworm (PEP 668) 外部管理环境须加该参数

# 2. 部署 YuNet ONNX 人脸检测模型至硬编码目录
sudo mkdir -p /home/jr/models
cd /home/jr/models
sudo wget https://github.com/opencv/opencv_zoo/raw/main/models/face_detection_yunet/face_detection_yunet_2023mar.onnx

# 3. 运行主程序
cd "2、软件代码/project"
python3 main.py
```

访问推流监视界面：在同局域网设备浏览器打开：`http://<树莓派IP>:5000`

---

## 9. 工程排障与维护对照手册

| 故障现象 | 潜在排查方向 | 推荐诊断手段与解决对策 |
| :--- | :--- | :--- |
| **启动抛出 `FileNotFoundError: /home/jr/models/...`** | 模型文件缺失或路径不匹配 | 确认模型已下载至 `/home/jr/models/`，或在 `camera_yunet.py` 传入实际路径 |
| **抛出 `OSError: [Errno 19] No such device (can0)`** | SPI-CAN 底层驱动未激活 | 检查 `/boot/config.txt` 中的 `mcp2515-can0` 叠加项及 GPIO25 连线，执行 `ls /sys/class/net/can0` |
| **电机通电使能后剧烈抖动震荡** | 控制极性反向或增益过大 | 检查 `YAW_DIRECTION` 是否为 `-1`；若改动机械结构导致镜像，需反转对应极性 |
| **激光测距读数始终显示 `-- cm`** | 串口权限缺失或波特率不匹配 | 执行 `sudo usermod -a -G dialout $USER` 授予串口权限；检查硬件 TX/RX 是否交叉连接 |
| **Web 监视页面提示连接超时拒绝** | 端口冲突或防火墙阻断 | 检查端口占用 `sudo netstat -tlpn \| grep 5000`；确认树莓派防火墙已放行 5000 端口 |

---

## 10. 工程全量资料索引

### 10.1 专项工程技术规范文档矩阵 (Specialized Technical Specs)

除本根目录系统总览文档外，项目在 `docs/` 目录下配套构建了 4 份工业级专项技术规范文档，供不同工程分工的研发人员深度查阅与二次开发：

| 规范文档路径 | 核心技术范畴与对应章节 | 重点覆盖内容概要 |
| :--- | :--- | :--- |
| 📄 [`docs/HARDWARE_DESIGN.md`](docs/HARDWARE_DESIGN.md) | **电路底板与电气工程规范** | LM2596S-5.0 开关降压热设计、MCP2515+SN65HVD230 总线接口、嘉立创 epro2 真实器件 BOM 全量提取明细、地平面隔离与供电拓扑 |
| 📄 [`docs/PROTOCOL_SPEC.md`](docs/PROTOCOL_SPEC.md) | **通信总线与底层协议规范** | CubeMars GL40 11 位标准帧 ID 编址、模式 2 float32 速度帧打包、TFmini Plus 9 字节 UART 协议双字节滑动窗口同步有限状态机 (FSM) |
| 📄 [`docs/CONTROL_AND_VISION.md`](docs/CONTROL_AND_VISION.md) | **视觉感知与闭环控制理论** | IMX219+YuNet ONNX 端侧推理管线、针孔透视成像投影与雅可比微分矩阵、带死区非线性速度控制律相平面动力学、单周期时间预算与有效控制率（标称 20 ms 门限 / 实测 ≈22.7 ms、约 44~45 Hz） |
| 📄 [`docs/DEPLOY_AND_DEBUG.md`](docs/DEPLOY_AND_DEBUG.md) | **系统部署、缺陷加固与排障** | 树莓派底层设备树 SPI/UART 配置、SocketCAN 1Mbps 接口管理、4 项源码缺陷深度审计与热补丁修复代码、开机自检 (POST) 故障隔离决策树 |

---

### 10.2 全工程代码与多媒体资产树

```
跟踪云台相关资料/
├── 1、硬件电路/
│   └── ProPrj_跟踪云台电路板.epro2          # 嘉立创 EDA 专业版完整 PCB 与原理图源文件
├── 2、软件代码/
│   └── project/
│       ├── camera_yunet.py               # Picamera2 图像捕获与 YuNet 人脸检测封装类
│       ├── gimbal_can.py                 # SocketCAN 1Mbps 电机驱动及速度帧编解码
│       ├── main.py                       # 50Hz 双轴闭环视觉跟踪控制主程序
│       ├── mjpeg_stream.py               # 基于 Flask 的局域网 Web 视频推流服务端
│       └── tfmini_uart.py                # TFmini Plus 串口后台异步测距驱动类
├── 3、3D模型/                             # 结构件 SolidWorks SLDPRT/SLDASM 及通用 STEP 模型
│   ├── GL40驱动电路板.SLDPRT
│   ├── IMX219摄像头模块（130度）1.SLDPRT
│   ├── Raspberry Pi Zero 2 W.SLDPRT
│   ├── TOF sensor TF MINI PLUS v2.SLDPRT
│   └── 装配体1.SLDASM                    # 完整双轴联调总装 SolidWorks 装配体工程
├── docs/                                 # 专项技术文档体系与纯矢量图表资产
│   ├── HARDWARE_DESIGN.md                # 专用电路底板硬件设计与电气工程规范
│   ├── PROTOCOL_SPEC.md                  # 通信总线与底层协议技术规范
│   ├── CONTROL_AND_VISION.md             # 视觉感知算法与双轴闭环控制理论分析
│   ├── DEPLOY_AND_DEBUG.md               # 系统部署、源码缺陷加固与工程排障指南
│   └── images/                           # 17 幅纯矢量 SVG 高清无损图表
│       ├── system_architecture.svg       # 全链路系统架构拓扑矢量图 (走廊清晰布线)
│       ├── gimbal_mechanical_structure.svg# 双轴云台机械 CAD 正交立面与轴系矢量图
│       ├── hardware_schematic_block.svg  # 底板原理图拓扑与芯片接口矢量图 (纯净无乱码)
│       ├── can_frame_phy_spec.svg        # CAN 2.0B 物理层位时序与 GL40 报文全解图
│       ├── control_loop_block_diagram.svg# 经典控制工程离散闭环控制方块图
│       ├── optical_geometry_projection.svg# 针孔成像几何与同轴测距投影空间矢量图 (引线卡标注)
│       ├── perf_radar_advanced.svg       # 8维设计 vs 实测工程雷达对比图 (纯矢量高对比度)
│       ├── phase_portrait.svg            # 2D 状态相平面收敛流线场图 (纯矢量)
│       ├── tracking_heatmap.svg          # 视场速度矢量模长等高线热力图 (纯矢量)
│       ├── time_budget_donut.svg         # 22.7ms 实测时间预算与算力消耗环形图 (纯矢量)
│       ├── protocol_bitfields.svg        # CAN 与 UART 协议二进制位域映射图 (纯矢量)
│       ├── control_law_comparison.svg    # 控制律特性曲线与物理限幅对比图 (纯矢量)
│       ├── step_response_dynamic.svg     # 阶跃响应与突发扰动抑制仿真图 (纯矢量)
│       └── timing_pipeline.svg           # 单周期端到端处理流水线时序图 (纯矢量)
├── tools/                                # 绘图自动化与工程辅助脚本工具包
│   ├── README.md                         # 工具脚本使用与重新渲染说明
│   ├── gen_professional_svgs.py          # 工业级标准 SVG 矢量架构图生成程序
│   ├── gen_supplementary_svgs.py         # CAN 时序与机械 CAD 结构矢量图生成脚本
│   ├── gen_clean_donut_svg.py            # 时间预算纯矢量无重叠环形图生成器
│   └── fix_6_svg_overflows.py            # 流线场/热力图/阶跃响应纯矢量图生成脚本
├── 【协议手册】GL40模组驱动使用说明.pdf       # CubeMars 官方驱动器通信与电气规格说明书
└── README.md                             # 跟踪云台工程系统技术规范总览主文档
```

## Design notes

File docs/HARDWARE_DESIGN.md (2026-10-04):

# 跟踪云台专用电路底板硬件设计与电气工程规范 (HARDWARE_DESIGN)

[]()
[]()
[]()
[]()
[]()

[]()
[]()
[]()

---

## 目录 (Table of Contents)

- [1. 需求分析与架构设计 (Requirements & Architecture)](#1-需求分析与架构设计-requirements--architecture)
  - [1.1 硬件需求规格与追溯矩阵](#11-硬件需求规格与追溯矩阵)
  - [1.2 系统顶层电气互联拓扑](#12-系统顶层电气互联拓扑)
- [2. 电路拓扑解构与接口定义](#2-电路拓扑解构与接口定义)
  - [2.1 电路底板拓扑结构矢量全景 (SVG 矢量图)](#21-电路底板拓扑结构矢量全景-svg-矢量图)
  - [2.2 树莓派 40-Pin 扩展引脚电气连接定义](#22-树莓派-40-pin-扩展引脚电气连接定义)
  - [2.3 原理图功能分区划分](#23-原理图功能分区划分)
  - [2.4 供电电源树拓扑](#24-供电电源树拓扑)
  - [2.5 网络节点实测统计](#25-网络节点实测统计)
- [3. BOM 元器件选型与降额分析](#3-bom-元器件选型与降额分析)
  - [3.1 元器件真实性核验说明](#31-元器件真实性核验说明)
  - [3.2 嘉立创工程真实器件明细表](#32-嘉立创工程真实器件明细表)
  - [3.3 关键元器件应力降额计算](#33-关键元器件应力降额计算)
- [4. LM2596 降压稳压级深度设计](#4-lm2596-降压稳压级深度设计)
  - [4.1 Buck 开关拓扑与占空比计算](#41-buck-开关拓扑与占空比计算)
  - [4.2 滤波电感选型与纹波电流设计](#42-滤波电感选型与纹波电流设计)
  - [4.3 转换效率与功耗测算](#43-转换效率与功耗测算)
  - [4.4 热设计与覆铜散热过孔阵列](#44-热设计与覆铜散热过孔阵列)
  - [4.5 环路稳定性与阻尼特性分析](#45-环路稳定性与阻尼特性分析)
- [5. MCP2515 + SN65HVD230 总线接口设计](#5-mcp2515--sn65hvd230-总线接口设计)
  - [5.1 控制器与物理层收发器互联](#51-控制器与物理层收发器互联)
  - [5.2 CAN 位时序理论模型](#52-can-位时序理论模型)
  - [5.3 1Mbps 位时序配置与 8MHz 晶振适配分析](#53-1mbps-位时序配置与-8mhz-晶振适配分析)
  - [5.4 验收滤波与屏蔽寄存器设置](#54-验收滤波与屏蔽寄存器设置)
  - [5.5 物理层收发特性与斜率控制](#55-物理层收发特性与斜率控制)
  - [5.6 SPI Mode 0,0 读写事务时序](#56-spi-mode-00-读写事务时序)
- [6. PCB Layout 与抗干扰设计规范 (EMC/EMI)](#6-pcb-layout-与抗干扰设计规范-emcemi)
  - [6.1 布局分区与层叠设计原则](#61-布局分区与层叠设计原则)
  - [6.2 功率回路最小化与 SW 开关节点约束](#62-功率回路最小化与-sw-开关节点约束)
  - [6.3 模拟地与数字地单点 0Ω 汇接设计](#63-模拟地与数字地单点-0ω-汇接设计)
  - [6.4 CAN 差分对阻抗控制与布线要求](#64-can-差分对阻抗控制与布线要求)
  - [6.5 MIPI CSI-2 敏感差分对走线防护](#65-mipi-csi-2-敏感差分对走线防护)
  - [6.6 晶振时钟电路布局规范](#66-晶振时钟电路布局规范)
- [7. 电源完整性分析 (PI)](#7-电源完整性分析-pi)
  - [7.1 陶瓷退耦网络阻抗特性](#71-陶瓷退耦网络阻抗特性)
  - [7.2 开关电源纹波与高频噪声抑制](#72-开关电源纹波与高频噪声抑制)
  - [7.3 负载阶跃与瞬态响应跌落分析](#73-负载阶跃与瞬态响应跌落分析)
- [8. 硬件验证与测试把关规范](#8-硬件验证与测试把关规范)
  - [8.1 测试验证策略](#81-测试验证策略)
  - [8.2 硬件测试项目矩阵](#82-硬件测试项目矩阵)
  - [8.3 关键电气测试点基准表](#83-关键电气测试点基准表)
- [9. 可靠性工程分析 (FMECA)](#9-可靠性工程分析-fmeca)
- [10. 机械装配配合与配置管理](#10-机械装配配合与配置管理)
  - [10.1 机械装配物理配合要求](#101-机械装配物理配合要求)
  - [10.2 硬件配置项 (HW-CI) 清单](#102-硬件配置项-hw-ci-清单)
  - [10.3 工程偏差登记与后续改进项](#103-工程偏差登记与后续改进项)
- [附录 参考资料](#附录-参考资料)

---

## 1. 需求分析与架构设计 (Requirements & Architecture)

### 1.1 硬件需求规格与追溯矩阵

按 ARP4754A 系统需求分解思想与 DO-254 硬件需求捕获实践，将系统级需求分解为底板硬件需求。每条需求给出**验证方法**（T=测试 Test、A=分析 Analysis、D=演示 Demonstration、I=检查 Inspection）与**追溯指向**（本文档的落实章节 / BOM 位号），构成需求双向追溯矩阵的上游。

| REQ-ID | 需求描述 | 来源 | 验证方法 | 追溯指向 |
| :--- | :--- | :--- | :--- | :--- |
| **REQ-HW-001** | 动力输入接口通过 CN1（XT30PW-M）接入 8.0V~32.0V DC 外部动力母线，额定承受 24V 连续工况，反接不产生不可逆损坏 | 系统输入 | I+A | §2.4、§3.2、§9 |
| **REQ-HW-002** | U1（LM2596SX-5.0）将 VIN 降压并输出 VCC = 5.0V/3A 额定母线，为树莓派 Zero 2 W、IMX219 摄像头、TFmini Plus 供电 | 系统架构 | T | §4、§8.2 |
| **REQ-HW-003** | VCC 输出负载调整率：全负载范围 0~2A 内，VCC 电压维持在 4.85V~5.25V | 系统架构 | T | §8.3 |
| **REQ-HW-004** | VCC 输出纹波：2A 额定负载下 $V_{pp} < 50\text{mV}$（150kHz 开关基波及其谐波） | 系统架构 | T | §7.2、§8.3 |
| **REQ-HW-005** | U2（MCP2515T-I/ST）经树莓派 SPI0（Mode 0,0）访问，片选 CE0（Pin24），中断 INT 接 GPIO25（Pin22） | 系统架构 | I+D | §2.2、§5.6 |
| **REQ-HW-006** | CAN 物理层由 U3（SN65HVD230DR）驱动 CANH/CANL，满足 ISO 11898-2 差分电平；总线位速率目标 1Mbps（适配现状见 §5.3 偏差项 DEV-HW-01） | 系统架构 | T+A | §5、§8.2 |
| **REQ-HW-007** | X1（8.000MHz，SMD3225）为 U2 提供振荡基准，常温频偏满足 CAN 位同步预算（总偏差 ≤ ±0.4%） | 系统架构 | A+T | §5.3、§8.3 |
| **REQ-HW-008** | 原理图区分功率/数字地 GND 与模拟地 AGND，经 R3/R4（0Ω）单点汇接，电机大电流回流不流经晶振回路 | EMC 设计 | A+I | §6.3 |
| **REQ-HW-009** | 元器件应力满足 MIL-STD-1547 降额思想：结温、电压、功耗降额并形成书面结论 | 可靠性 | A | §3.3 |
| **REQ-HW-010** | 底盘最恶劣工况（VIN=24V、VCC=5V/2A、TA=60℃）下 U1 结温不超过设计限值 110℃ | 可靠性 | A+T | §4.4、§8.2 |
| **REQ-HW-011** | CAN 差分网络特性阻抗 120Ω ±10%，双绞线两端各布置 120Ω 终端，等长等距走线 | EMC 设计 | I | §6.4 |
| **REQ-HW-012** | CN2（GH1.25 系列）提供激光雷达 UART 与电机 CAN 信号引出，机械保持力满足装配要求 | 机械接口 | I | §10.1 |
| **REQ-HW-013** | 静放电阻抗满足 DO-160G §25 静电放电防护能力（总线引脚 HBM 等级由 U3 固有 ±16kV 提供） | 环境适应 | T | §8.2 |
| **REQ-HW-014** | 底板通过 J1（2.54mm 2×20 排母）与树莓派 Zero 2 W 电气/机械对位，Pin1 标记明确、无错位风险 | 机械接口 | I | §10.1 |

### 1.2 系统顶层电气互联拓扑

```mermaid
flowchart LR
    subgraph PWR["① 动力域 Power Domain"]
        BAT["外部动力母线 8~32V DC"]
        XT30["CN1: XT30PW-M<br/>(大电流输入公头)"]
        GL40Y["GL40 #1 偏航轴 Yaw<br/>FOC + ADRC"]
        GL40P["GL40 #2 俯仰轴 Pitch<br/>FOC + ADRC"]
        BAT --> XT30
        XT30 -->|"24V 母线<br/>直达电机驱动器"| GL40Y
        XT30 -->|"24V 母线<br/>直达电机驱动器"| GL40P
    end
    subgraph PSU["② 稳压域 Regulation Domain"]
        U1["U1: LM2596SX-5.0/NOPB<br/>TO-263-5, 150kHz, 5V/3A"]
        XT30 -->|"VIN"| U1
        U1 -->|"VCC = 5.0V/3A"| VCC["VCC 5V 母线"]
    end
    subgraph SOC["③ 主控域 Controller Domain"]
        RPI["树莓派 Zero 2 W<br/>BCM2710A1 (J1: 40P 排母)"]
        VCC -->|"Pin2/Pin4"| RPI
        RPI -->|"片上 LDO"| V3["3V3 3.3V 母线"]
    end
    subgraph CANBUS["④ CAN 总线域 Bus Domain"]
        U2["U2: MCP2515T-I/ST<br/>TSSOP-20, SPI-CAN 控制器"]
        X1["X1: 8.000MHz 晶振+SMD3225"]
        U3["U3: SN65HVD230DR<br/>SOIC-8, 3.3V 收发器"]
        U4["U4: SN65HVD231DR<br/>SOIC-8, 备用通道"]
        BUS["CANH / CANL 双绞总线<br/>ISO 11898-2"]
        V3 --> U2
        V3 --> U3
        V3 --> U4
        X1 --> U2
        RPI <-->|"SPI0: MOSI/MISO/SCLK/CE0<br/>(Pin19/21/23/24)"| U2
        RPI <-->|"INT: GPIO25 (Pin22)"| U2
        U2 <-->|"TXCAN/RXCAN"| U3
        U3 -->|"差分驱动"| BUS
        U4 -.->|"预留并联"| BUS
        BUS --> GL40Y
        BUS --> GL40P
    end
    subgraph SNS["⑤ 传感与接口域 Sensor & I/O Domain"]
        TF["TFmini Plus 激光雷达"]
        CAM["IMX219 摄像头 (CSI-2)"]
        SR["12 路精密导电滑环"]
        RPI <-->|"UART: TXD(8)/RXD(10)"| TF
        RPI <-->|"MIPI CSI-2 差分"| CAM
        CN2["CN2: GH1.25 系列插座"]
        BUS --- CN2
        UAUX["UART/CAN 信号引出"] --- CN2
        CN2 --- SR
    end
```

---

## 2. 电路拓扑解构与接口定义

本项目硬件承载板工程文件为 `1、硬件电路/ProPrj_跟踪云台电路板.epro2`，采用嘉立创 EDA 专业版进行原理图设计与双层 PCB Layout。作为树莓派 Zero 2 W 的专用扩展底板，该电路板承担三大核心使命：

1. **大电流动力供电分配与高压降压稳压**：外部 8V~32V DC 动力母线经 CN1 引入，直接供给两台 CubeMars GL40 FOC 无刷云台电机，同时 U1 将其转换为 5V/3A 稳定母线供给树莓派主控与外设；
2. **高速 SPI 转 CAN 现场总线桥接**：将树莓派 BCM2710A1 的硬件 SPI0 扩展为遵循 ISO 11898-2 物理层的标准差分 CAN 总线（目标 1Mbps 波特率，适配现状见 §5.3），驱动双轴电机；
3. **传感器接口与机械安装法兰物理转接**：集成北醒 TFmini Plus 激光雷达 UART 插座、IMX219 摄像头固定与 12 路精密导电滑环走线引出。

### 2.1 电路底板拓扑结构矢量全景 (SVG)

硬件电路底板原理图拓扑结构

### 2.2 树莓派 40-Pin 扩展引脚电气连接定义

底板通过 J1（2.54mm 2×20 双排母）与树莓派 Zero 2 W 的 40-Pin GPIO 对接。下表为全引脚电气分配（NC = 本底板未连接保留）：

```
+-----------------------------------------------------------------------------+
|              树莓派 Zero 2 W  40-Pin GPIO 接头 (J1: 2.54mm 2x20)             |
+------------+---------------------------------+---+--------------------------+
| Pin        | 信号 / 底板网络                  |Pin| 信号 / 底板网络          |
+------------+---------------------------------+---+--------------------------+
| 1 (3V3)    | [3.3V 逻辑基准]                  | 2 (5V) | [VCC: LM2596 输出]  <==|
| 3 (SDA)    | [NC 保留]                        | 4 (5V) | [VCC: LM2596 输出]  <==|
| 5 (SCL)    | [NC 保留]                        | 6 (GND)| --- [系统总接地 GND]    |
| 7 (GP4)    | [NC 保留]                        | 8 (TXD)| =>> [UART TX -> TFmini] |
| 9 (GND)    | --- [系统总接地 GND]             |10 (RXD)| <<= [UART RX <- TFmini] |
|11 (GP17)   | [NC 保留]                        |12 (GP18)|[NC 保留]                |
|13 (GP27)   | [NC 保留]                        |14 (GND)|--- [系统总接地 GND]    |
|15 (GP22)   | [NC 保留]                        |16 (GP23)|[NC 保留]                |
|17 (3V3)    | [3.3V 逻辑基准]                  |18 (GP24)|[NC 保留]                |
|19 (MOSI)   | >> [SPI0 MOSI -> MCP2515 SI]     |20 (GND)|--- [系统总接地 GND]    |
|21 (MISO)   | << [SPI0 MISO <- MCP2515 SO]     |22 (GP25)| <== [MCP2515 /INT]      |
|23 (SCLK)   | >> [SPI0 SCLK -> MCP2515 SCK]    |24 (CE0) | >> [SPI0 CE0 -> CS]     |
|25 (GND)    | --- [系统总接地 GND]             |26 (CE1) | [NC 保留]               |
|27 (ID_SD)  | [EEPROM NC]                      |28 (ID_SC)|[EEPROM NC]              |
|29 (GP5)    | [NC 保留]                        |30 (GND)|--- [系统总接地 GND]    |
|31 (GP6)    | [NC 保留]                        |32 (GP12)|[NC 保留]                |
|33 (GP13)   | [NC 保留]                        |34 (GND)|--- [系统总接地 GND]    |
|35 (GP19)   | [NC 保留]                        |36 (GP16)|[NC 保留]                |
|37 (GP26)   | [NC 保留]                        |38 (GP20)|[NC 保留]                |
|39 (GND)    | --- [系统总接地 GND]             |40 (GP21)|[NC 保留]                |
+------------+---------------------------------+---+--------------------------+
关键网络: 3V3=Pin1/17  VCC=Pin2/4  GND=Pin6/9/14/20/25/30/34/39
          SPI: MOSI=19 MISO=21 SCLK=23 CE0=24   INT=GPIO25=Pin22
          UART: TXD=Pin8 RXD=Pin10 (TFmini Plus, 115200bps 8N1)
```

### 2.3 原理图功能分区划分

原理图按"功率域 / 稳压域 / 数字域 / 模拟域 / 接口域"五区划分，域间通过受控的网络接口互联，防止高 dv/dt、大 di/dt 回路侵入敏感区域：

| 分区代号 | 功能分区 | 包含位号 / 网络 | 电气特征 | 隔离与耦合策略 |
| :---: | :--- | :--- | :--- | :--- |
| **①** | 动力/功率区 | CN1(XT30PW-M)、VIN 母线、U1 功率回路 | 8~32V、瞬态峰值 10A 级 | 短而粗的功率回路；与数字区保持物理间距 |
| **②** | 稳压区 | U1(LM2596SX-5.0)、VCC 5V 母线、C3/C4 | 150kHz 开关、5V/3A | SW 节点监视 (§6.2)；散热焊盘阵列 (§4.4) |
| **③** | 数字域 | J1(40P)、U2(MCP2515) SPI/RST/INT、U3/U4 TXD/RXD、3V3 轨 | 3.3V 逻辑、SPI ≤10MHz | 完整地平面参考；与功率区分区走线 |
| **④** | 模拟域 | X1(8MHz)、C1/C2(10pF)、AGND 岛 | nA~mA 级、谐振敏感 | 0Ω (R3/R4) 单点汇接 GND (§6.3) |
| **⑤** | 接口域 | CN2(GH1.25 系列)、CANH/CANL、UART、CSI-2、滑环引出 | 差分/高频串行 | 差分对等长等距；与 SW ≥10mm (§6.5) |

### 2.4 供电电源树拓扑

```text
供电电源树拓扑 (Power Delivery Tree):
[外部动力电池 / 稳压电源 8V ~ 32V DC]
        |
        +--> [CN1: XT30PW-M 卧式输入公头] --------+
        |                                        |
        |   (24V 母线直达电机, 不经过板载稳压)      |
        |            +--> [GL40 Yaw 偏航轴驱动器 (24V 母线, 额定2A/峰值10A)]
        |            +--> [GL40 Pitch 俯仰轴驱动器 (24V 母线, 额定2A/峰值10A)]
        |
        +--> [U1: LM2596SX-5.0/NOPB (TO-263-5, 150kHz Buck)]
                     |  5.0V / 3A 额定输出 (典型负载 ~2A)
                     v
              [VCC 5V 系统母线 (Pin2/Pin4)]
                     |
                     +--> [树莓派 Zero 2 W (5V 输入)] --> [BCM2710A1 核心]
                     +--> [IMX219 摄像头模组 5V 偏置]
                     +--> [TFmini Plus 激光雷达 5V 供电]
                     |
              [树莓派片上 LDO 输出 3.3V 轨]
                     +--> [3V3 母线] --+--> [U2: MCP2515T-I/ST (Vdd=3.3V)]
                                        +--> [U3: SN65HVD230DR (Vcc=3.3V, 主通道)]
                                        +--> [U4: SN65HVD231DR (Vcc=3.3V, 备用)]
```

---

## 3. BOM 元器件选型与降额分析

### 3.1 元器件选型规范说明

> [!NOTE]
> 本 BOM 清单提取自嘉立创 EDA 专业版工程数据库 (`ProPrj_跟踪云台电路板.epro2`)。
> CAN 总线 120Ω 终端匹配电阻位于外部总线线缆两端，底板不设板载终端。任何元器件的增删改须更新硬件配置基线（§10.2）。

### 3.2 嘉立创工程真实器件明细表

"失效率温度特性"按 MIL-HDBK-217 零件计数法思路给出工程定性结论（半导体失效率主要由温度应力驱动，随 TA 每升高 10℃ 约按 Arrhenius 关系倍增数量级放大）；"封装热阻"为 JEDEC 标准测试板典型估算值，用于热分析初算，投产前以厂内热仿真/实测复算。

| 位号 | 元件型号 / 规格参数 | 封装 | 数量 | 关键参数 | 失效率温度特性 / 老化机理 | 封装热阻 θJA / θJC |
| :--- | :--- | :--- | :---: | :--- | :--- | :--- |
| **U1** | `LM2596SX-5.0/NOPB` | TO-263-5 | 1 | 150kHz，输出 5V/3A，输入上限 40V，固定 5.0V 输出 | 功率半导体，失效率最高项；结温每 +10℃ 失效率约翻倍；主要失效：功率开关应力疲劳、闩锁 | **≈50℃/W / ≈2℃/W** |
| **U2** | `MCP2515T-I/ST` | TSSOP-20 (0.65mm) | 1 | 3.3V 供电，SPI ≤10MHz，CAN 2.0B，带 3 发 2 收缓冲 + 6 验收滤波 | CMOS 数字，温升失效率中等；敏感项：寄存器配置锁死、SPI 总线冲突 | ≈110℃/W / ≈35℃/W (估) |
| **U3** | `SN65HVD230DR` | SOIC-8 (150mil) | 1 | 3.3V 单电源，≤1Mbps，ISO 11898-2，总线 ESD >±16kV HBM，最多 120 节点，斜率可调 | 总线收发器，应力主要为总线瞬态（感性抛负载、ESD）；主要失效：总线引脚 EOS | ≈160℃/W (估) |
| **U4** | `SN65HVD231DR` | SOIC-8 (150mil) | 1 | 同 U3，附带超低功耗待机/睡眠模式 | 同 U3；当前为预留并联，不承载失效风险 | ≈160℃/W (估) |
| **X1** | `X32258MSB4SI` | SMD3225-4P | 1 | 8.000MHz 无源石英晶体，配 C1/C2 构成皮尔斯振荡 | 老化为主（石英谐振子缓慢老化，典型每年数 ppm 量级）；失效率随温度与驱动电平上升 | ≈150℃/W (估) |
| **C1, C2** | `CL10C100JB8NNNC` (10pF/50V) | 0603 | 2 | C0G（Ⅰ类）介质，±5%（J 档），直流偏压下容值几乎无衰减 | 陶瓷 Ⅰ 类，几乎无老化；失效模式为机械开裂/热冲击（装配应力） | ≈130℃/W (估) |
| **C3, C4** | `CGA0805X5R106K500MT` (10µF/50V) | 0805 | 2 | X5R（Ⅱ类）介质，K 档 ±10%；直流偏压下容值部分衰减（以厂商 DC-bias 曲线复算） | 陶瓷 Ⅱ 类，长期直流偏压+高温加速老化（容值衰减、绝缘电阻下降——寿命 ∝ exp(Ea/kT)） | ≈130℃/W (估) |
| **R1, R2** | `FRC0603J103TS` (10kΩ ±5%) | 0603 | 2 | 1/10W 厚膜，J 档 ±5% | 失效模式：阻值漂移、开路/短路；功耗利用率极低，失效率可忽略 | ≈120℃/W (估) |
| **R3, R4** | `RC0603FR-070RL` (0Ω) | 0603 | 2 | 0Ω 跨接电阻，额定电流约 0.5A 量级 | 作为选焊跳线；虚焊/脱焊为装配类风险，见 §9 | ≈120℃/W (估) |
| **CN1** | `XT30PW-M` | 卧式直插 | 1 | 额定 15A 连续 / 30A 瞬态；接触电阻约 1mΩ 量级 | 大电流连接器，发热集中于接触电阻；失效模式：接触电阻上升导致过热打火 | — |
| **CN2** | `GH1.25-6PWT` / `HC-1.25-2PWT` 系列 | GH 1.25mm 卧贴 | 多组 | 1.25mm 间距卧式贴片，UART/CAN 信号引出 | 小间距贴片连接器；失效模式：插拔磨损、错插 | — |
| **J1** | `2.54mm 2×20 Pin Header` | 双排母 (40P) | 1 | 2.54mm 标准间距，40P | 机械插拔疲劳；失效模式：插孔松弛、错位 | — |

### 3.3 关键元器件应力降额计算

参照 MIL-STD-1547 及航空航天工程惯例，对底板关键器件执行应力降额核算。降额判定准则：实际工作应力 ≤ 额定值 × 降额因子，且降额结论须书面化（不合格项登记偏差单，见 §10.3）。

| 降额项 | 额定 / 极限 | 本设计最坏工作点 | 应力利用率 | 降额判定 | 结论与处置 |
| :--- | :--- | :--- | :---: | :--- | :--- |
| U1 输入电压 | Vin,max = 40V | VIN = 32V | 80% | **不满足** 常用 60% 电压降额准则 | 实际系统 VIN 标称 24V（利用率 60%）；32V 上限仅在母线瞬态允许短时出现。保留为设计裕量说明，不作偏差 |
| U1 结温 | Tj,max(工作) = 125℃（绝对最大 150℃） | Tj 需 ≤ 110℃（降额 12%） | 见 §4.4 计算 | **条件满足** | 满足的前提是 θja,eff ≤ 17.7℃/W，须散热焊盘+过孔阵列实现（§4.4） |
| C1/C2 电压 | 50V | X1 引脚直流电平 ≈ VDD/2 ≈ 1.65V | 3.3% | **满足**（余量 ≫70%） | C0G 介质无直流偏压容值衰减，谐振频率确定性高 |
| C3/V4 输入侧电压 | 50V | 32V（母线瞬态上限） | 64% | **边界不满足** 50% 降额准则 | 偏差单 DEV-HW-03：标称 24V 工作点利用率 48% 合格；瞬态 32V 时短时超限，陶瓷电容无电解液干涸机理、耐压裕量仍充裕，判定可接受并登记 |
| C4 输出侧电压 | 50V | 5V | 10% | **满足** | — |
| R1/R2 功耗 | 0603 额定 1/10W(100mW) | P = V²/R = 3.3²/10⁴ ≈ 1.1mW | 1.1% | **满足** | 即使 3V3 轨被误拉到 5.5V 故障态，P=3.0mW 仍 ≪ 额定 |
| R3/R4 电流 | 0603 0Ω 载流约 0.5A 量级 | AGND 回路电流 µA 级 | ≪1% | **满足** | 0Ω 桥仅承载晶振地回流（§6.3），载流余量巨大 |
| U2/U3/U4 供电电压 | 3.6V (最大) | 3V3 轨 3.25~3.35V | 93% | **边界关注** | 树莓派 3V3 轨输出能力充足且已有监测判据（§8.3 TP_3V3）；无低压差风险，登记为关注项 |

**降额计算示例（R1/R2 中断上拉电阻）**：

$$
P_{R} = \frac{V_{3V3}^2}{R} = \frac{(3.3\,\text{V})^2}{10\,\text{k}\Omega} \approx 1.09\,\text{mW}
$$

物理意义：INT 引脚常态被树莓派拉高为低电平，仅在 MCP2515 开漏输出有效时导通，电阻功耗为 μA~mA 级；即使计入闩锁/短路故障态，0603 封装的 100mW 额定功耗仍留有两个数量级裕量。来源：MIL-STD-1547 电阻功耗降额 ≤50% 的思想在工程设计上转化为"最坏故障态可承受"。

---

## 4. LM2596 降压级深度设计

### 4.1 Buck 开关拓扑与占空比计算

U1（LM2596SX-5.0/NOPB，TO-263-5 贴片封装）构成固定 5V 输出的 Buck 降压变换器。上管导通时输入储能至电感 L、续流二极管关断；上管关断时电感电流经续流二极管续流。理想伏秒平衡给出占空比：

$$
D = \frac{V_{\text{out}}}{V_{\text{in}}} = \frac{5.0\,\text{V}}{24.0\,\text{V}} \approx 0.2083 \quad (20.83\%)
$$

式中参数说明：
- $V_{\text{out}}$：Buck 变换器输出稳压值，设定为标称 $5.0\,\text{V}$；
- $V_{\text{in}}$：动力母线直流输入电压，标称工况为 $24.0\,\text{V}$；
- $D$：理想开关占空比（无量纲）。

> [!NOTE]
> **工程参数修正**
> - **导通压降修正**：计入片内达林顿双极型开关管的饱和压降 $V_{\text{SAT}} \approx 1.3\,\text{V}$ 后，实际有效占空比修正为：
>   

$$
D_{\text{eff}} = \frac{V_{\text{out}} + V_{\text{SAT}}}{V_{\text{in}}} \approx \frac{5.0 + 1.3}{24.0} \approx 26.25\%
$$

> - **导通模式判据**：当负载电流大于临界连续电流 $I_{\text{LB}} = \Delta I_L / 2$ 时，回路处于连续导通模式 (CCM)。本系统在 $2.0\,\text{A}$ 额定负载下稳定运行于 CCM。

### 4.2 滤波电感选型与纹波电流设计

电感电流纹波由伏秒平衡与电感定义导出（CCM 稳态，上管导通期间）：

$$
\Delta I_L = \frac{(V_{\text{in}} - V_{\text{out}}) \cdot D}{f_{\text{sw}} \cdot L} = \frac{(24.0\,\text{V} - 5.0\,\text{V}) \times 0.2083}{150\,\text{kHz} \cdot L}
$$

式中参数说明：
- $\Delta I_L$：电感高频峰峰值纹波电流（单位：$\text{A}$）；
- $f_{\text{sw}}$：内部固定振荡器开关频率，典型值为 $150\,\text{kHz}$；
- $L$：储能滤波电感标称感值（单位：$\text{H}$）。

工程惯例（TI 参考设计与电源设计手册通用准则）要求电感电流纹波率为额定负载电流的 **20%~40%**——过低则负载阶跃响应慢、瞬态差；过高则 RMS 损耗与输出纹波恶化。

| 电感取值 | ΔIL 计算 | 纹波率 ΔIL/Iout(2A) | 判定 |
| :---: | :--- | :---: | :--- |
| L = 33µH | $\frac{19\times0.2083}{150\text{k}\times33\text{µ}}=0.80\text{A}$ | 40% | 处于准则上限 |
| **L = 47µH（建议）** | $\frac{19\times0.2083}{150\text{k}\times47\text{µ}}=0.56\text{A}$ | **28%** | **落入 20%~40% 最优区** |
| L = 68µH | 0.39A | 19.4% | 略低于准则下限 |

对应临界负载电流 $I_{LB} = \Delta I_L/2 = 0.28\text{A}$，即 VCC 母线负载约 1.4W 以上均维持 CCM；树莓派空载/待机（180~320mA，§1.1/REQ）进入轻载 DCM，属正常工作模式（LM2596 轻载自动进入突发/断续，仍维持稳压）。

> [!WARNING]
> **电感与续流回路实证说明**
> 当前底板贴片 BOM 仅包含 U1 开关芯片本体，未集成独立功率电感与肖特基二极管。
> 系统工程形态采用“外挂集成 LM2596 降压模块承担 5V 主供电，板载预留芯片引脚与覆铜”的双重分流拓扑。若后续改版需集成完整分立 Buck，须经正式工程变更 (ECN) 选型，不得沿用任何非设计元器件。

### 4.3 转换效率与功耗测算

以典型设计点（Vin=24V，Vout=5V，Iout=2A）核算。输入功率、芯片耗散功率与效率的关系：

$$
P_{out}=V_{out}\cdot I_{out}=10\,\text{W}, \qquad P_{d}=\frac{P_{out}}{\eta}(1-\eta)=P_{out}\frac{1-\eta}{\eta}
$$

| 效率场景 | η | 输入功率 Pin | 芯片耗散 Pd | 说明 |
| :--- | :---: | :---: | :---: | :--- |
| 保守（低温/轻载偏差） | 78% | 12.82W | **2.82W** | 25℃ 室温附近、占空比 ~21% 的典型曲线低端 |
| 典型 | 80% | 12.50W | 2.50W | 数据手册效率曲线中值 |
| 良好 | 82% | 12.20W | 2.20W | 铜箔散热良好时改善 |

即本设计热分析按 **Pd ≈ 2.8W（最坏）** 取包络，与旧文档"η≈75~82%，Pd≈2.82W"结论一致并对齐到保守端。

### 4.4 热设计与覆铜散热过孔阵列

TO-263-5（贴片 D2PAK 类）封装的热流路径：结→铜夹架/焊盘（θjc ≈ 2℃/W）→PCB 焊盘铜箔→过孔阵列→底层铺铜→环境空气（θja，无风冷约 50℃/W）。**瓶颈在结到环境路径**。

结温方程：

$$
T_j = T_A + P_d \cdot \theta_{ja,\text{eff}}
$$

式中参数说明：
- $T_j$：LM2596 芯片核心结温（单位：$^\circ\text{C}$）；
- $T_A$：云台腔体内部工作环境温度（设计最恶劣上限按 $+60.0\,^\circ\text{C}$ 校核）；
- $P_d$：芯片自身耗散的热功率（保守包络值取 $2.82\,\text{W}$）；
- $\theta_{ja,\text{eff}}$：考虑 PCB 散热覆铜与过孔阵列后的等效结到环境热阻（单位：$^\circ\text{C/W}$）。

| 工况 | θja,eff | Tj 计算 | 判定 |
| :--- | :--- | :--- | :--- |
| 裸封装、最小焊盘、无风 | 50℃/W | $T_A{=}25\text{℃}: 25+2.82\times50=166\text{℃}$ | **超限**（>125℃ 工作上限） |
| TA=60℃ 最恶劣 + 裸封装 | 50℃/W | $60+141=201\text{℃}$ | **严重超限**（超过 150℃ 绝对最大） |
| **顶层 ≥1300mm² 连续铜 + 12×φ0.3mm 过孔阵列** | **≈18~20℃/W** | $T_A{=}60\text{℃}: 60+2.82\times19\approx113\text{℃}$ | **临界满足**（设计限值 110℃，余量 3~10℃） |
| 同上 + 外挂模块分流（板载仅 ≈1A） | ≈19℃/W | Pd≈1.5W → $60+28\approx88\text{℃}$ | **满足**（裕量充裕） |

**强制热设计规则（落实到 Layout 检查单）**：

1. U1 底部裸露焊盘必须 ≥1300mm² 顶层铜承接，阵列过孔 ≥12 个（φ0.3mm，间距 ≤3mm）贯通至底层并底层镜像铺铜；
2. 过孔内壁镀铜连通（散热过孔），禁止阻焊覆盖散热焊盘主区域；
3. U1 远离 X1/C1/C2 晶振回路（≥15mm）与 40P 排母高热器件；
4. 5V 实际负载设计包络：双 GL40 待机（各 ≤50mA）+ 树莓派峰值（Zero 2 W 5V 输入峰值约 1.2A）+ 传感器 ≈1.3A → 典型 Pd≈1.9W，Tj≈96℃@60℃；2A 额定点作为 V&V 验证点（§8.2 TP-03）。

### 4.5 环路稳定性与阻尼特性分析

LM2596 为电压型 PWM 控制器，内部误差放大器 + 锯齿振荡器闭环。输出网络的极点/零点位置决定环路相位裕度：

- **LC 输出双重极点**：$f_{LC} = \frac{1}{2\pi\sqrt{LC}} = \frac{1}{2\pi\sqrt{47\text{µH}\times10\text{µF}}} \approx 7.3\,\text{kHz}$
- **输出电容 ESR 零点**：$f_{z,ESR} = \frac{1}{2\pi\cdot ESR\cdot C} = \frac{1}{2\pi\times5\,\text{m}\Omega\times10\,\text{µF}} \approx 3.2\,\text{MHz}$
- **穿越频率**：电压型 Buck 典型 $f_c \lesssim f_{sw}/10 \approx 15\,\text{kHz}$，且应低于 $f_{LC}$ 以保证双重极点处的相位衰减被环路增益衰减覆盖。

**结论与工程处置**：板载仅 2×10µF 陶瓷输出（C3/C4）时，$f_{LC}$ ≈7.3kHz 靠近穿越频率设计窗口，而 $f_{z,ESR}$ ≈3.2MHz 远在穿越频率之外，**无法为环路提供 ESR 零点阻尼/相位提升**；按 TI 参考设计，LM2596 稳定工作要求输出侧具备 100µF 级以上低 ESR 储能电容。处置：(a) 5V 主变换由外挂集成模块承担（其输出电容为百 µF 级，环路由模块厂方保证）；(b) 板载 U1 限定为轻载辅助支路（Pd ≤1.5W，同时缓解 §4.4 热压力）；(c) 若在板内分立实现完整 Buck，须按 TI 参考电路补足输出电容并复测负载阶跃响应（§7.3）。

---

## 5. MCP2515 + SN65HVD230 总线接口设计

### 5.1 控制器与物理层收发器互联

| 信号 | MCP2515 (U2) 引脚 | SN65HVD230 (U3) 引脚 | 网络 / 备注 |
| :--- | :--- | :--- | :--- |
| TXCAN | Pin 1 (TXCAN) | Pin 1 (TXD) | 数字发送输出 |
| RXCAN | Pin 2 (RXCAN) | Pin 4 (RXD) | 数字接收输入 |
| VDD/VSS | Pin 9 / 8、19（AVDD/AVSS 独立模拟供电） | Pin 3 (VCC) / 2 (GND) | 3V3 / GND |
| OSC1/OSC2 | Pin 6 / 7 | — | 外接 X1 + C1/C2（皮尔斯振荡，AGND 参考） |
| SI/SO/SCK/CS | Pin 17/18/16/15 | — | SPI0：MOSI(19)/MISO(21)/SCLK(23)/CE0(24) |
| /INT | Pin 12（开漏） | — | 上拉 R2 至 3V3，接 GPIO25 (Pin22) |
| /RESET | Pin 3（低有效） | — | 上拉 R1 至 3V3，正常运行时维持高电平 |
| CANH/CANL | — | Pin 7 / 6 | 差分总线；U4(231) 可并联扩展 |

### 5.2 CAN 位时序理论模型

CAN 位时间由若干时间量子 TQ 构成，寄存器 CNF1/CNF2/CNF3 编程定义（来源：MCP2515 数据手册 DS20001801J）：

$$
\begin{aligned}
T_Q &= \frac{2 \times (\text{BRP} + 1)}{F_{\text{OSC}}} \\
\text{NBT} &= \text{Sync\_Seg} + \text{Prop\_Seg} + \text{Phase\_Seg1} + \text{Phase\_Seg2} \\
\text{BitRate} &= \frac{1}{\text{NBT} \times T_Q}, \qquad \text{SamplePoint} = \frac{\text{Sync\_Seg} + \text{Prop\_Seg} + \text{Phase\_Seg1}}{\text{NBT}} \times 100\%
\end{aligned}
$$

式中参数说明：
- $T_Q$：时间量子 (Time Quantum)，位时序计算的最小基准时间片（单位：$\text{s}$）；
- $\text{BRP}$：波特率预分频系数 (Baud Rate Prescaler, 取值 $0 \sim 63$)；
- $F_{\text{OSC}}$：外部输入无源晶振振荡频率（标称为 $8.000\,\text{MHz}$）；
- $\text{NBT}$：标称位时间内的总时间量子数（Nominal Bit Time, 单位：$T_Q$）；
- $\text{SamplePoint}$：位采样点在位周期中的相对时间位置（推荐区间 $75.0\% \sim 87.5\%$）。

- $T_Q$：由 BRP（CNF1 波特率预分频）与振荡器频率决定，是位时序最小划分单元；
- $NBT$：标称位时间（TQ 数），CAN 规范推荐 8~25 TQ；
- $SP$：采样点在位时间中的相对位置，一般取 70%~87.5%，本设计取 75%。

### 5.3 1Mbps 位时序配置与 8MHz 晶振适配分析

**目标配置（1Mbps，8TQ/位，SP=75%）**：SYNC=1 + PropSeg=2 + PS1=3 + PS2=2，SJW=1TQ，BRP=0 → $T_Q=125\,\text{ns}$，$NBT\times T_Q=8\times125\,\text{ns}=1\,\mu\text{s}$ → **1Mbps**，$SP=(1+2+3)/8=75\%$。

| 寄存器 | 字段配置 | 目标值 | 编码 |
| :--- | :--- | :--- | :--- |
| CNF1 | SJW=1TQ, BRP=0 | 0x00 | SJW<1:0>=00, BRP<5:0>=0 |
| CNF2 | BTLMODE=1(PS2 长度由 CNF3 定义), SAM=0(单采样), PHSEG1=2(=PS1−1), PRSEG=1(=PropSeg−1) | **0x91** | 1_0_010_001 |
| CNF3 | WAKFIL=0, PHSEG2=1(=PS2−1), SOF=0 | **0x10** | 0_001_00 |

**晶振适配分析（关键工程结论）**：BOM 中 X1 为 `X32258MSB4SI`（**8.000MHz**），而 Linux 设备树覆盖层配置 `oscillator=8000000`、目标位速率 1Mbps。按上式：

$$
F_{OSC}=8\,\text{MHz},\ BRP=0 \Rightarrow T_Q = \frac{2}{8\,\text{MHz}} = 250\,\text{ns} \Rightarrow NBT_{\min}=8\text{TQ} \Rightarrow BR_{max}\ \text{(8TQ)} = 500\,\text{kbps}
$$

MCP2515 位时间最小 5TQ（SYNC=1+Prop=1+PS1=1+PS2=2），即使按最小位时间，$F_{OSC}=8$MHz 时可达上限也仅约 800kbps，**无法建立 1Mbps 位时序**。即"8.000MHz 晶振 + 1Mbps"存在物理不相容，已登记为偏差项：

> **偏差项 DEV-HW-01（必须闭环）**：BOM X1=8.000MHz 与系统需求 REQ-HW-006/007（1Mbps）不相容。处置选项（须由 ECN 决策）：
> (a) 若实测证实 X1 实际为 16MHz（丝印核对 + 示波器频率计数，§8.3 TP_OSC），则目标配置 {CNF1=0x00, CNF2=0x91, CNF3=0x01} 直接成立，1Mbps 有效；
> (b) 若 X1 确为 8.000MHz，则维持该器件时总线最高 500kbps（同寄存器配置、BRP=0 → 8TQ×250ns=2µs），GL40 驱动器支持 500kbps，属可运行降级；
> (c) 或改贴 16MHz 晶振实现 1Mbps。三种处置均须同步更新 HW-CI 与本文档 Rev B。

### 5.4 验收滤波与屏蔽寄存器设置

MCP2515 提供 6 个验收滤波器（RXF0~RXF5）与 2 个屏蔽寄存器（RXM0/RXM1）。RXF0/RXF1 作用于接收缓冲 RXB0（经 RXM0 屏蔽），RXF2~RXF5 作用于 RXB1（经 RXM1）。本系统报文集合（详见《PROTOCOL_SPEC》）：GL40 反馈帧 ID=0x000（目的地 Master）、偏航轴指令/回传 0x201、俯仰轴指令/回传 0x202，全部为 11-bit 标准帧（EXIDE=0）。

**硬件滤波示例配置**（接收 Motor ID 段 0x000~0x3FF 全部标准帧）：

| 寄存器 | 配置值 | 说明 |
| :--- | :--- | :--- |
| RXF0SIDH/L | 0x000 | 匹配 ID 0x000~0x1FF（含 0x000 反馈帧） |
| RXF1SIDH/L | 0x200 | 匹配 ID 0x200~0x3FF（含 0x201、0x202） |
| RXM0SIDH/L | 0x700 | 屏蔽位仅比较 ID 高 3 位（bit10:8） |
| RXF0/RXF1 的 EXIDE 位 | 0 | 仅验收标准帧，拒绝扩展帧 |

- 滤波判据：当 (接收 ID AND RXM) == (RXF AND RXM) 时报文被接收。RXM0=0x700 时同组两芯片片选共享 SPI 总线地址 0x200 段 0x000~0x1FF，满足主控只关心 0x000/0x201/0x202 的流量画像；
- **工程说明**：Linux `mcp251x` 驱动通常将 RXM 清零（全通），帧过滤交由 SocketCAN 协议层完成；硬件滤波器作为**总线风暴工况下的第一道防线**保留价值——当 MCU 侧异常导致协议层过载时，硬件滤波器可限定只有本节点关心的 ID 进入 FIFO，降低 U2 锁死风险（§9）。

### 5.5 物理层收发特性与斜率控制

| 特性 | 参数 / 行为 | 来源与工程意义 |
| :--- | :--- | :--- |
| 供电 | 单 3.3V（3.0~3.6V） | 直接挂 3V3 轨，与 U2/树莓派逻辑电平天然兼容，无需 5V↔3.3V 转换 |
| 速率 | 最高 1Mbps | 与 CAN 系统目标位速率匹配（适配见 §5.3） |
| 电平 | ISO 11898-2 差分：隐性时 CANH/CANL ≈2.5V，显性时 CANH≈3.5V、CANL≈1.5V，$V_{diff}\approx2.0\text{V}$ | ISO 11898-2:2016；判据列入 §8.3 |
| 节点数 | 高输入阻抗，最多 120 节点 | 双 GL40 + 底板收发器远未耗尽节点预算 |
| ESD | 总线引脚 HBM ESD > ±16kV | 满足 DO-160G §25 静电放电要求的固有裕度（REQ-HW-013） |
| 斜率控制 | Pin 8 (Rs) 可经外部电阻设定驱动边沿时间 | **本工程不贴 Rs 电阻**（BOM 实证），即选择最短边沿的高速模式，与目标总线速率匹配 |
| U4 (HVD231) | 同系列 + 超低功耗待机/睡眠模式 | 预留并联节点接口；当前不焊接/不驱动，作为扩展配置项 |

### 5.6 SPI Mode 0,0 读写事务时序

```text
SPI Mode 0,0 读写事务与 MCP2515 硬件中断触发时序:
            __                                                                    __
/CS (CE0)     \__________________________________________________________________/
                 _   _   _   _   _   _   _   _   _   _   _   _   _   _   _   _
SCLK        ____/ \_/ \_/ \_/ \_/ \_/ \_/ \_/ \_/ \_/ \_/ \_/ \_/ \_/ \_/ \_/ \_
            ____   ___________________________   ___________________________   _____
MOSI (SI)   ____X_<______ 命令字节 (如 0x02) _>_X_<______ 寄存器地址 (0x31) _>_X_____
            __________________________________   ___________________________   _____
MISO (SO)   XXXXXXXXXXXXXXXXXXXXXXXXXXXXXXXXXX\_X_<______ 读取数据字节 (0xAA) _>_X_____
            ______________________________________                               ___
/INT (GPIO25)                                     \_____________________________/
                                                   ^ CAN 帧成功接收，触发低电平中断
```

时序要点：CPOL=0/CPHA=0（空闲低、第一沿采样）；命令字节 0x02/0x03 = 读/写指令；SPI 时钟上限受 U2 规格约束（≤10MHz，树莓派 SPI0 建议 ≤10MHz）；/INT 低电平有效、开漏，经 R2 上拉，树莓派以 GPIO25 下降沿中断响应。

---

## 6. PCB Layout 与抗干扰设计规范 (EMC/EMI)

### 6.1 布局分区与层叠设计原则

双层板（顶层+底层）条件下，以**分区布线与单点接地**补偿缺少完整地平面的局限：

1. 顶层：功率回路（CN1→U1→VCC）+ 数字区 + 模拟岛；底层：镜像回流铜皮；
2. 按 §2.3 五分区顺序布放，功率区与数字区之间留 ≥3mm 隔离沟（无铜）；
3. 所有信号优先单端参考完整地铜皮；差分对例外（§6.4）；
4. 载流计算按 IPC-2221：VIN 干线（2A 负载折算输入电流 ≈3A）+50% 裕量 → 铜厚 1oz 下走线宽度 ≥25mil；电机母线瞬态 10A 走线按 §7.3 瞬态预算核算。

### 6.2 功率回路最小化与 SW 开关节点约束

Buck 功率回路（输入电容→上管→地，续流二极管→电感→输入电容）携带 150kHz 三角波电流与开关边沿（上升时间几十 ns 量级）高频谐波，是底板首要骚扰源（Ott：回路面积决定辐射与地弹）：

1. **SW 节点铜箔最短化**：U1 的 SW 引脚到电感/续流路径的长度 **≤15mm**，且不得走锐角；
2. SW 节点下方及周边 **≥3mm 范围内不布设其它网络**，禁止跨越 AGND 岛上方；
3. 输入/输出电容紧贴 U1 对应引脚（输入电容距 VIN/GND 引脚 ≤3mm；输出电容距 VCC 焊盘 ≤3mm）；
4. 功率回路面积最小化：VIN→C3→U1→SW→续流→电感→Cout→地，闭环面积尽可能压缩；
5. 底层预留完整功率地铜皮，SW 高频回流就近返回，避免借道数字地。

### 6.3 模拟地与数字地单点 0Ω 汇接设计

GL40 电机相线 PWM 切换产生数安培级高频瞬变电流（di/dt 极大），若与晶振/SPI 敏感回路共地阻抗耦合，将同时污染模拟振荡回路与数字总线：

| 地网络 | 承载 | 用途 |
| :--- | :--- | :--- |
| **GND**（功率/数字地） | CN1 动力回路、U1 功率回路、J1 数字地、U2/U3/U4 逻辑地 | 工作电流主回流通路 |
| **AGND**（模拟地岛） | 仅 X1/C1/C2 振荡回路 | 与 U2 OSC 引脚就近短接，面积最小化 |

汇接原理：AGND 与 GND 通过 R3/R4（0Ω 贴片电阻）**单点双向汇接**——0Ω 电阻相对直接覆铜提供可诊断的工程断点（可焊开以隔离故障、测量地弹），同时保证直流等电位；晶振回路地回流（μA 级）不流经电机大电流路径，电机噪声也不倒灌晶振区域。检查项：AGND 岛任何其它位置不得再与 GND 相连（开尔文测试验证）。

### 6.4 CAN 差分对阻抗控制与布线要求

1. **终端**：双绞线**两端各 120Ω**（总线特性阻抗 120Ω ±10%）；总线上等效跨接 2×120Ω=60Ω， CANH/CANL 静态电阻测量判据 ≈60Ω（§8.2 TP-08）。**底板 BOM 不含板载 120Ω 终端电阻**——终端随线缆/驱动器侧实现；
2. **等长**：CANH/CANL 对内长度差 ≤2.5mm（对应 1Mbps 位周期 1µs 的相位偏差 <0.15TQ 量级，远小于再同步能力；500kbps 下载余量更大）；
3. **等距**：线距沿线恒定，避免阻抗突变；换层时两口过孔成对且位置对称（过孔数 ≤2）；
4. **拐角**：45° 斜切或圆弧，禁止 90° 直角；
5. **回流路径**：差分对下方保持连续地皮，禁止跨分割区；离开 GND 岛的过孔间距 ≥3 倍线宽。

### 6.5 MIPI CSI-2 敏感差分对走线防护

IMX219 的 CSI-2 差分对速率最高约 1Gbps 量级，对串扰最敏感：

1. **与 SW 节点防护间距 ≥10mm**（含跨层投影距离），不得平行走线；若不可避免交叉，须垂直跨越且跨越点远离 SW 电感端；
2. CSI-2 对与 UART/CAN 数字信号距离 ≥3 倍线宽；
3. CSI-2 连接器区域保持净空，底层完整地皮，不得从下方走 150kHz/300kHz 功率谐波密集回路；
4. 排线与 CSI-2 连接器的压接按厂商规范执行，避免阻抗不连续。

### 6.6 晶振时钟电路布局规范

1. X1 靠近 U2 的 OSC1/OSC2 引脚，晶振引脚到芯片走线 **≤8mm**，不得有分支/过孔；
2. X1 下方投影区**禁止任何走线与覆铜**（净空 ≥2mm），并以 AGND 戒严环包围；
3. C1/C2 紧贴 X1 两端（≤3mm），到 AGND 的回路最短；负载电容校核：C1/C2 各 10pF 串联得 5pF，叠加 MCP2515 OSC 输入电容与 PCB 杂散（合计约 3~5pF）后，晶振等效负载电容约 8~10pF——选型时以 X3225 系列器件规格书规定的负载电容为准核对牵引量（pulling tolerance），确保常温频偏满足 CAN 位同步预算（REQ-HW-007）；
4. **去耦电容安装电感与谐振**：C3/C4（0805、10µF）安装电感（焊盘+过孔合计约 0.6~1.5nH）决定了退耦高频段行为：

$$
f_{SRF}=\frac{1}{2\pi\sqrt{L_{ESL}\cdot C}}=\frac{1}{2\pi\sqrt{1.2\,\text{nH}\times10\,\text{µF}}}\approx1.45\,\text{MHz}
$$

自谐振点 1.45MHz ≫ 150kHz 开关频率，电容在开关纹波频段呈容性、有效退耦；超过 f_SRF 后呈感性、阻抗回升——故两颗电容应就近安装（VIN/VCC 引脚 ≤3mm）、并以最短回路接地，安装过孔贴电容焊盘内侧。U2/U3/U4 的 3V3 就近退耦依赖树莓派 3V3 轨本身的低阻特性与既有布局，登记为关注项（§10.3）。

---

## 7. 电源完整性分析 (PI)

### 7.1 陶瓷退耦网络阻抗特性

| 维度 | C0G（C1/C2，10pF） | X5R（C3/C4，10µF） |
| :--- | :--- | :--- |
| 介质类别 | Ⅰ 类（温度稳定） | Ⅱ 类（高容值密度） |
| 温度系数 | ≈0 ±30ppm/℃ | ±15%（−55~85℃） |
| 直流偏压效应 | 无 | **有**：0805/10µF/50V 在 5V 工作点容值衰减约 5~10%，32V 瞬态点衰减更显著（以厂商 DC-bias 曲线复算，Dev-HW-03 相关） |
| 角色 | 谐振基准元件（频偏确定性） | 储能/退耦（容值优先） |

### 7.2 开关电源纹波与高频噪声抑制

输出纹波由 ESR 项与容值项两部分构成，按叠加合成：

$$
\Delta V_{ESR}=\Delta I_L\cdot ESR \approx 0.56\,\text{A}\times5\,\text{m}\Omega \approx 2.8\,\text{mV}
$$

$$
\Delta V_C=\frac{\Delta I_L}{8\cdot f_{sw}\cdot C}=\frac{0.56}{8\times150\,\text{k}\times10\,\text{µ}}\approx46.7\,\text{mV}\ (\text{单侧}\,10\,\text{µF})
$$

纹波谱系：基波 150kHz 及其奇次谐波（450kHz/750kHz…）为主能量，叠加 SW 上升沿（几十 ns）激起的高频振铃（数 MHz~数十 MHz）。结论：单侧 10µF 保守估算 46.7mV + ESR 项 ≈47mV，**逼近 50mV 判据（REQ-HW-004）**；若 C3/C4 并联于输出侧（20µF）则降至 ≈23mV。→ 列入验证项 TP-04 实测裁定（§8.2），并为外挂集成模块承担 5V 主变换的方案（§4.5）提供论据。

### 7.3 负载阶跃与瞬态响应跌落分析

**输入侧源阻抗预算**：GL40 加速瞬态单轴峰值 10A、双轴合计 20A 级，要求在 VIN 汇流点跌落 <300mV（§8.3 判据）：

$$
Z_{source} \le \frac{\Delta V_{bus}}{I_{peak}} = \frac{0.3\,\text{V}}{20\,\text{A}} \le 15\,\text{m}\Omega
$$

即电池内阻 + 线束（按 14AWG 选型，长约 1m/双芯）+ XT30 接触电阻（约 1mΩ/触点量级）之和须 ≤15mΩ；汇流排导线按双电机 20A 峰值选 14AWG 及以上。

**热插拔浪涌**：CN1 带电接入时，C3/C4（24V 侧 10µF）充电电流 $I=C\cdot dv/dt$，若接入过程 10µs 内充至 24V，峰值 ≈24A，逼近 XT30 瞬态 30A 上限且会在触点间拉弧。→ 操作规程：上电前连接、断电后拔下（V&V TP-12 验证，程序化掉电）。

**输出侧瞬态**：树莓派负载阶跃（约 0.3A/数 µs）时，仅由 10µF 吸纳的开环估算 $\Delta V \approx I\cdot dt/C \approx 0.3\text{A}\times5\,\mu\text{s}/10\,\mu\text{F}\approx0.15\,\text{V}$；闭环环路（外挂模块）在数 μs 内接管，|ΔV| 落入 §8.3 TP_5V 判定带。该瞬态裕量依赖外挂模块的输出大电容，是 §4.5 处置方案 (a) 的 PI 侧佐证。

---

## 8. 硬件验证与测试把关规范

### 8.1 测试验证策略

按 DO-254 验证思想：每条 REQ-HW 至少被一种方法覆盖（T/A/D/I），测试结果须形成记录并闭环到 HW-CI。状态约定：P=通过、F=不通过、PEND=待执行。

### 8.2 硬件测试项目矩阵

| TP-ID | 测试项 | 对应 REQ | 方法 | 仪器 / 设备 | 验收判据 | 状态 |
| :--- | :--- | :--- | :--- | :--- | :--- | :--- |
| TP-01 | 输入电压全范围扫描 | REQ-001 | T | 可调直流电源 0~40V | 8.0~32.0V 全段 VCC 稳压正常 | PEND |
| TP-02 | 恒压精度与负载调整率 | REQ-003 | T | 电子负载 + 6½位万用表 | 0~2A：4.85~5.25V | PEND |
| TP-03 | U1 额定功率点温升 | REQ-010 | T | 热电偶/红外热像 + 恒温箱 | 24V/2A/60℃：Tj（推算）≤110℃ | PEND |
| TP-04 | VCC 纹波测量 | REQ-004 | T | ≥200MHz 示波器（20MHz 带宽限制） | 2A 负载 $V_{pp}<50\text{mV}$ | PEND |
| TP-05 | SPI 寄存器读写遍历 | REQ-005 | D | 树莓派 + `candump`/自检脚本 | 全部可写寄存器回读一致 | PEND |
| TP-06 | CAN 总线闭环收发 | REQ-006 | T | CAN 分析仪（PCAN/CANable） | 1Mbps（或降级 500kbps，见 DEV-HW-01）误码率 0 | PEND |
| TP-07 | INT 中断响应 | REQ-005 | D | 逻辑分析仪 | 收帧后 ≤20µs 内 GPIO25 拉低 | PEND |
| TP-08 | 总线直流电阻 / 终端核查 | REQ-011 | I | 万用表 | CANH-CANL 静阻 ≈60Ω（两端 120Ω 并联） | PEND |
| TP-09 | OSC 频率与频偏 | REQ-007 | T | 频率计/示波器计数 | 8.000MHz（或实测 16MHz）；常温偏差 ≤±50ppm | PEND |
| TP-10 | ISO 11898-2 电平验证 | REQ-006 | T | 示波器差分探头 | 隐性 2.5V/2.5V；显性 3.5V/1.5V | PEND |
| TP-11 | ESD 考核（接触放电） | REQ-013 | T | ESD 模拟器（参照 DO-160G §25） | ±4kV 接触放电后功能不丧失、自恢复 | PEND |
| TP-12 | 反接/带电热插拔故障注入 | REQ-001 | T | 辅助开关 + 示波器 | 反接 ≤2s 不冒烟、无不可逆损坏；热插拔无触点粘连 | PEND |
| TP-13 | CAN 总线开路/短路故障注入 | REQ-006 | T | 故障注入夹具 | 收发器进入故障保护、树莓派侧软件可自愈 | PEND |
| TP-14 | 高低温循环贮存 | REQ-010/013 | T | 高低温箱（参照 DO-160G §4/§5） | −10℃~+60℃ 工作、−20~70℃ 贮存后功能正常 | PEND |

### 8.3 关键电气测试点基准表

| 测量测试点 | 关联网络 | 正常工作电平范围 | 示波器/万用表检测标准 |
| :--- | :--- | :--- | :--- |
| **TP_VIN** | 主动力输入 | 8.0V ~ 32.5V DC | 纹波 $V_{pp}<300\text{mV}$（含电机瞬态），无反接浪涌击穿 |
| **TP_5V** | U1/模块稳压输出 VCC | 4.85V ~ 5.25V DC | 2A 负载时纹波 $V_{pp}<50\text{mV}$；负载阶跃后 100µs 内回落入带 |
| **TP_3V3** | 树莓派 3.3V 轨 | 3.25V ~ 3.35V DC | 纹波 $V_{pp}<20\text{mV}$；超限触发软件降级 |
| **TP_OSC** | X1 晶振引脚 | 8.000MHz 正弦/削顶正弦波 | 频率偏差 ≤±50ppm；幅度满足 MCP2515 OSC 输入门限 |
| **TP_SPI** | SCLK/MOSI/MISO（Pin23/19/21） | 3.3V CMOS，SPI ≤10MHz | 无过冲 >VDD+0.3V；无振铃超限 |
| **TP_CANH** | 差分总线高 | 隐性 2.5V / 显性 3.5V | 差分 $V_{diff}=V_H-V_L\approx2.0\text{V}$ |
| **TP_CANL** | 差分总线低 | 隐性 2.5V / 显性 1.5V | 共模抗扰符合 ISO 11898-2；总线对地短路不损坏收发器 |

---

## 9. 可靠性工程分析 (FMECA)

方法：失效模式、影响与危害性分析（参考 SAE ARP4761 危害度分级与 MIL-HDBK-217 失效模式库思想）。危害度等级：**Ⅰ=灾难性、Ⅱ=严重、Ⅲ=较严重、Ⅳ=轻微**；RPN = S(1~5) × O(1~5) × D(1~5)，>60 须强制补偿措施闭环。

| ID | 失效模式 | 原因 | 局部影响 | 整机影响 | 危害度 | 检测方法 | 补偿措施 |
| :--- | :--- | :--- | :--- | :--- | :---: | :--- | :--- |
| F-01 | 晶振停振/不起振 | X1 虚焊、C1/C2 容值偏差、负载电容失配（§6.6） | U2 无时钟，CAN 收发停止 | 双轴失控（保持最后指令或停机），跟踪丢失 | Ⅱ | TP-09 频率测量；软件心跳超时（看门狗） | 装配工艺首检；软件总线超时保护（电机进入安全停机） |
| F-02 | MCP2515 锁死/寄存器跑飞 | SPI 总线冲突、ESD、软件时序违规 | CAN 中断不响应、报文丢弃 | 控制指令丢失 → 跟踪停滞 | Ⅱ | 心跳/看门狗；TP-05 寄存器回读 | 硬件滤波器分流总线流量（§5.4）；软件定时强制 /RESET 软复位流程 |
| F-03 | LM2596 过热失效 | 散热焊盘过小、TA>60℃、2A 满载 | 结温超限 → 热保护关断 | 5V 掉电，树莓派重启，云台失稳 | Ⅱ | TP-03 温升测试；温度监测 | 过孔阵列散热（§4.4）；外挂模块分流降额；软件降载 |
| F-04 | XT30 正负极反接 | 人为插反 | U1/收发器承受 −24V | 器件击穿冒烟，动力母线短路 | Ⅰ | TP-12 故障注入；目视极性标记 | 操作规程强制（先接后端后上电）；后续版本可增加防反接 TVS/串联 MOSFET（ECN 评估） |
| F-05 | CAN 总线开路 | 线缆断裂、接插件松动、滑环通道失效 | 某轴指令丢失 | 单轴失联 → 云台偏航轴保持/漂移 | Ⅲ | TP-08 电阻核查；总线错误帧监控 | GH1.25 卧贴加固（§10.1）；软件双轴互检与故障码上报（0xD 通讯丢失） |
| F-06 | CAN 总线短路（CANH-CANL / 对地） | 绝缘破损、金属异物 | 收发器饱和/发错帧 | 总线瘫痪 | Ⅱ | TP-13 故障注入；TEC/REC 错误计数 | U3 总线故障保护特性；节点自动 Bus-Off 隔离，其余节点不受影响 |
| F-07 | 静电放电（ESD） | 干燥环境人体触碰连接器 | 单次泄放 ≥kV 级 | 芯片潜在损伤或瞬时复位 | Ⅲ | TP-11（DO-160G §25） | U3 总线引脚 ±16kV HBM 固有防护；整机接地泄放路径 |
| F-08 | 0Ω 汇接电阻虚焊 | 装配应力、热循环 | AGND/GND 间阻抗漂移 | 晶振回路引入地弹噪声，偶发位错误 | Ⅲ | IPC-A-610 焊接检查；AOI | R3/R4 选焊冗余（双颗并联）；X -ray 抽检 |
| F-09 | C3/C4 容值衰减/开裂 | X5R 直流偏压、机械应力、热冲击 | 退耦能力下降 | 电源纹波超差、复位偶发 | Ⅳ | TP-04 纹波测量 |  voltage 裕量评估（DEV-HW-03）；贴装避板边 ≥3mm |

---

## 10. 机械装配配合与配置管理

### 10.1 机械装配物理配合要求

1. **J1 40P 排母对位**：Pin1（方焊盘/标记）朝板边外侧方向，与树莓派 Zero 2 W 板边基准对齐；建议叠高排母/支撑柱保证 ≥5mm 净空以兼顾 SoC 散热片与 CSI 排线折弯半径；对位销钉孔优先于纯目视；
2. **CN2 GH1.25 卧贴焊接**：1.25mm 小间距卧式贴片，焊盘按 IPC-2221 刀具设计；回流峰值温度与时间门窗执行厂商规范；焊后 AOI 检查连锡/虚焊；插接扭矩/拔出力按座规抽检；
3. **CN1 XT30PW-M 卧插**：卧式公头焊接于顶层，插拔方向朝板外；线束端 14AWG 硅胶线 + 压接（专用压线钳，拉脱力抽检），标识极性（红正黑负）；
4. **滑环走线约束**：12 路精密导电滑环（偏航轴过线）通道分配建议：CANH、CANL 各占 1 路（双绞成对）、5V、GND、UART_TX/RX 等；滑环转动寿命按整机任务剖面核算；滑环出线应力释放夹固定，避免焊点受扭；
5. GL40 电机（41×38mm，FOC+ADRC）安装法兰与底板定位孔配合，电机 XT30 (2+2) 电源/CAN 复合插座与 CN1 同规格体系，缩短定制线束。

### 10.2 硬件配置项 (HW-CI) 清单

| CI 项 | 基线内容 | 版本 / 标识 | 责任人 |
| :--- | :--- | :--- | :--- |
| HW-CI-01 | 原理图工程 `ProPrj_跟踪云台电路板.epro2` | epro2 专业版当前工程库版本 | 硬件组 |
| HW-CI-02 | BOM 基线（§3.2，13 位号） | 与本文档 Rev A 冻结 | 硬件组 |
| HW-CI-03 | PCB Gerber + 钻孔 + 叠层文件 | 以导出包 SHA 校验为准 | 硬件组 |
| HW-CI-04 | 器件库（符号/封装/3D） | 嘉立创库锁定版本 | 硬件组 |
| HW-CI-05 | 本文档（规范基线） | TRK-GMB-HW-SPEC-001 Rev A | 硬件架构组 |
| HW-CI-06 | 关联文档 | README §2、PROTOCOL_SPEC、CONTROL_AND_VISION、DEPLOY_AND_DEBUG | 各组 |
| HW-CI-07 | 验证记录（§8.2 执行件） | TP 记录随测试归档 | 测试组 |

### 10.3 工程偏差登记与后续改进项

| 偏差号 | 描述 | 影响 | 处置 / 责任方 | 状态 |
| :--- | :--- | :--- | :--- | :--- |
| DEV-HW-01 | X1=8.000MHz 与 1Mbps 需求物理不相容（§5.3） | 总线速率降级 500kbps 或改贴 16MHz | ECN 决策 + 频率实测 | **开放** |
| DEV-HW-02 | 板载输出电容仅 10~20µF，环路稳定性依赖外挂模块（§4.5/§7.2） | 板载 U1 限定轻载辅助支路 | 结构方案固定 + TP-04 复测 | 开放 |
| DEV-HW-03 | C3 输入侧电容 32V 瞬态时 64% 利用率超 50% 降额准则（§3.3） | 短时超限，陶瓷耐压余量可承受 | 登记接受 + 新批次可改 100V 额定 | 已接受 |
| DEV-HW-04 | U2/U3/U4 无专用就近退耦电容 | 依赖 Pi 3V3 轨低阻特性 | 下版 ECN 增补 100nF 就近电容 | 开放 |

---

## 附录 参考资料

1. RTCA DO-254 / EUROCAE ED-80, *Design Assurance Guidance for Airborne Electronic Hardware*, 2000.
2. SAE ARP4754A, *Guidelines for Development of Civil Aircraft and Systems*, 2010.
3. SAE ARP4761, *Guidelines and Methods for Conducting the Safety Assessment Process on Civil Airborne Systems and Equipment*, 1996.
4. MIL-HDBK-217F Notice 2, *Reliability Prediction of Electronic Equipment*（方法参考，工程可用 FIDES/IEC 62380 复核）.
5. MIL-STD-1547, *Electronic Parts, Materials, and Processes for Space and Launch Vehicles*.
6. IPC-2221B, *Generic Standard on Printed Board Design*.
7. RTCA DO-160G, *Environmental Conditions and Test Procedures for Airborne Equipment*.
8. IPC-A-610H, *Acceptability of Electronic Assemblies*.
9. ISO 11898-2:2016, *Road vehicles — Controller area network (CAN) — Part 2: High-speed medium access unit*.
10. Texas Instruments, *LM2596 Simple Switcher Power Converter Data Sheet*（SNVS118 系列）.
11. Microchip Technology, *MCP2515 Stand-Alone CAN Controller with SPI Interface Data Sheet*, DS20001801J.
12. Texas Instruments, *SN65HVD23x 3.3-V CAN Bus Transceivers Data Sheet*（ti.com/lit/ds/symlink/sn65hvd230.pdf）.
13. CubeMars, 《GL40模组驱动使用说明》V1.0.0, 2024-07-18.
14. Ott H. W., *Electromagnetic Compatibility Engineering*, Wiley, 2009.
15. Bogatin E., *Signal and Power Integrity — Simplified*, 3rd Ed., Pearson, 2018.
16. 工程事实源：`1、硬件电路/ProPrj_跟踪云台电路板.epro2`（位号、型号、封装、网络名的唯一真实来源）.

---

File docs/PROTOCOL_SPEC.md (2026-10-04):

# 跟踪云台通信总线与底层协议技术规范 (PROTOCOL_SPEC)


[]()
[]()
[]()
[]()
[]()

---

## 目录 (Table of Contents)

- [1. 协议体系概述与 OSI 分层映射](#1-协议体系概述与-osi-分层映射)
  - [1.1 双总线体系结构与分工](#11-双总线体系结构与分工)
  - [1.2 OSI 七层模型对照表](#12-osi-七层模型对照表)
  - [1.3 系统物理拓扑图](#13-系统物理拓扑图)
- [2. CAN 2.0B 核心机制深度解析](#2-can-20b-核心机制深度解析)
  - [2.1 帧类型总览与物理位时序](#21-帧类型总览与物理位时序)
  - [2.2 标准数据帧完整位域结构 (SVG 矢量图)](#22-标准数据帧完整位域结构-svg-矢量图)
  - [2.3 逐位非破坏性仲裁机制与竞争过程](#23-逐位非破坏性仲裁机制与竞争过程)
  - [2.4 位填充 (Bit Stuffing) 与最坏帧长推导](#24-位填充-bit-stuffing-与最坏帧长推导)
  - [2.5 差错校验机制与 CRC15 生成多项式](#25-差错校验机制与-crc15-生成多项式)
  - [2.6 错误界定与节点故障隔离状态机 (TEC/REC)](#26-错误界定与节点故障隔离状态机-tecrec)
  - [2.7 1Mbps 位时序与采样点参数计算](#27-1mbps-位时序与采样点参数计算)
- [3. CubeMars GL40 应用协议全析](#3-cubemars-gl40-应用协议全析)
  - [3.1 11-Bit ID 编址规则与三种控制模式](#31-11-bit-id-编址规则与三种控制模式)
  - [3.2 电机生命周期控制命令集 (DLC = 8)](#32-电机生命周期控制命令集-dlc--8)
  - [3.3 模式 2 速度控制帧封装与 IEEE-754 浮点手算推导](#33-模式-2-速度控制帧封装与-ieee-754-浮点手算推导)
  - [3.4 驱动器反馈遥测帧 (Feedback Packet) 与 12-bit 解包公式](#34-驱动器反馈遥测帧-feedback-packet-与-12-bit-解包公式)
  - [3.5 GL40 驱动器电气规格速查表](#35-gl40-驱动器电气规格速查表)
  - [3.6 总线负载率与吞吐裕量分析](#36-总线负载率与吞吐裕量分析)
  - [3.7 PWM 输入模式与 CAN 模式对比](#37-pwm-输入模式与-can-模式对比)
- [4. 北醒 TFmini Plus UART 串行测距协议全析](#4-北醒-tfmini-plus-uart-串行测距协议全析)
  - [4.1 9 字节定长二进制数据包布局映射表](#41-9-字节定长二进制数据包布局映射表)
  - [4.2 校验和算法数学定义与抗误码分析](#42-校验和算法数学定义与抗误码分析)
  - [4.3 双 0x59 滑动窗口帧同步 FSM 状态机 (Mermaid)](#43-双-0x59-滑动窗口帧同步-fsm-状态机-mermaid)
  - [4.4 字节流粘包半包处理策略与超时语义](#44-字节流粘包半包处理策略与超时语义)
  - [4.5 内部温度字段解析公式与物理量提取](#45-内部温度字段解析公式与物理量提取)
  - [4.6 串口链路时序预算 (100Hz 数据率)](#46-串口链路时序预算-100hz-数据率)
- [5. 嵌入式 Linux SocketCAN 实现层](#5-嵌入式-linux-socketcan-实现层)
  - [5.1 can.Message 报文对象结构](#51-canmessage-报文对象结构)
  - [5.2 bus.send 发送超时语义与 ENOBUFS 防护](#52-bussend-发送超时语义与-enobufs-防护)
  - [5.3 candump / cansend 报文格式与实战命令集](#53-candump--cansend-报文格式与实战命令集)
  - [5.4 协议要素与源码逐行追溯表](#54-协议要素与源码逐行追溯表)
- [6. 控制周期报文时序流水线](#6-控制周期报文时序流水线)
- [7. 电机通信协议辨析 (与 29 位扩展帧协议的差异)](#7-电机通信协议辨析-与-29-位扩展帧协议的差异)
- [8. 双协议二进制位域综合总图 (SVG 矢量图)](#8-双协议二进制位域综合总图-svg-矢量图)
- [9. 参考资料](#9-参考资料)
- [附录 常用术语与缩略语](#附录-常用术语与缩略语)

---

## 1. 协议体系概述与 OSI 分层映射

### 1.1 双总线体系结构与分工

云台系统包含两条核心硬件通信总线，分别驱动动力执行机构与环境感知传感器：

1. **CAN 现场总线 (Controller Area Network)**
   - 物理层遵循 **ISO 11898-2:2016 高速差分双绞线**规范，固定波特率 **1,000,000 bps (1 Mbps)**。
   - 主控 (树莓派) 作为网络中的 **Master 节点**，以 **11 位标准数据帧 (Standard Frame, `is_extended_id=False`)** 向两台 CubeMars GL40 驱动器下发速度矢量指令；驱动器通过控制帧触发回传 8 字节遥测反馈帧至 Master ID `0x000`。
2. **TTL UART 异步串行总线**
   - 连接树莓派主硬件串口 `/dev/serial0`（PL011 UART），参数 **115,200 bps, 8-N-1**。
   - 以 **100 Hz** 帧率单向接收北醒 TFmini Plus 激光测距传感器输出的 **9 字节定长二进制报文**。

| 维度 | CAN 总线（电机轴） | UART 链路（激光雷达） |
| :--- | :--- | :--- |
| 波特率 | 1,000,000 bps | 115,200 bps |
| 电气形式 | 差分双绞线（显性/隐性电平） | 单端 TTL（高/低电平） |
| 帧格式 | 11-bit 标准帧 + 8 字节数据段 | 9 字节定长二进制包 |
| 通信方向 | 双向多主竞争式（本项目主从单发） | 单向流式（传感器 → 主控） |
| 传输频率 | 50 Hz 控制周期（T = 20 ms） | 100 Hz 输出帧率（T = 10 ms） |
| 差错控制 | CRC15 + ACK + 格式检查 + 错误界定 | 帧头同步 + 累加校验和 + 物理门限过滤 |

### 1.2 OSI 七层模型对照表

CAN 与 UART 均为"物理层 + 数据链路层"型协议，其上由各厂商私有应用协议补齐高层语义：

| OSI 层级 | CAN 总线（GL40 电机轴） | UART 链路（TFmini Plus） |
| :--- | :--- | :--- |
| **L7 应用层** | CubeMars GL 驱动协议：控制模式命令帧 / 生命周期命令帧 / 遥测反馈帧 | 北醒 TFmini 协议：9 字节测距帧（距离 / 强度 / 温度） |
| **L6 表示层** | IEEE-754 float32 小端编码；12-bit 定点位打包 | uint8/uint16 无符号小端整型打包 |
| **L5 会话层** | —（无会话概念，指令即发即用） | —（常开字符流） |
| **L4 传输层** | —（单帧自含语义，无分片重组） | —（定长帧自含语义） |
| **L3 网络层** | 11-bit 仲裁段节点寻址（`0x201` / `0x202`，回传 `0x000`） | 点对点直连，无寻址概念 |
| **L2 数据链路层** | **ISO 11898-1:2015**：LLC/MAC 子层、逐位仲裁、CRC15、ACK、错误界定（TEC/REC 三态） | 字符级组帧：双 `0x59` 帧头同步 + 定长 9 字节 + 累加校验和 |
| **L1 物理层** | **ISO 11898-2:2016**：高速收发器、显性/隐性差分电平、120 Ω 终端匹配 | TTL 异步串行：1 起始位 + 8 数据位 + 1 停止位，无校验位 |

> **设计注记**：CAN 标准体系（ISO 11898-1/-2）只定义 L1/L2，因此本规范第 2 章按 Bosch CAN 2.0B 规范展开链路层机制，第 3 章按 CubeMars GL 系列手册（V1.0.0）展开应用层。UART 链路同理，北醒协议自组帧结构（见第 4 章），设计风格可参照 IEC 61162 系列海事数字接口"定长二进制帧 + 校验和"的工程惯例。

### 1.3 系统物理拓扑图

```mermaid
flowchart TB
    subgraph HOST["主控节点 (Master) — 树莓派"]
        APP["应用层任务<br/>跟踪控制循环 (50 Hz)"]
        PY["gimbal_can.py<br/>python-can / SocketCAN"]
        TF["tfmini_uart.py<br/>pyserial 后台线程"]
        APP --> PY
        APP --> TF
    end

    PY -->|"can0 (PF_CAN socket)"| DRV1["CAN 收发器<br/>ISO 11898-2"]
    DRV1 -->|"CAN_H / CAN_L<br/>差分双绞线 1 Mbps"| BUS((CAN 总线))

    subgraph BUSNET["1 Mbps CAN 总线段"]
        R1["120Ω<br/>终端电阻"] --- BUS
        BUS --- N1["GL40 #1<br/>Yaw 偏航轴<br/>发送目标 ID 0x201"]
        BUS --- N2["GL40 #2<br/>Pitch 俯仰轴<br/>发送目标 ID 0x202"]
        BUS --- R2["120Ω<br/>终端电阻"]
    end

    N1 -.->|"反馈帧 → 0x000"| BUS
    N2 -.->|"反馈帧 → 0x000"| BUS

    TF -->|"/dev/serial0<br/>115200 8N1"| SEN["TFmini Plus ToF 激光测距<br/>9 字节帧 @ 100 Hz"]
```

要点：

- **CAN 段**：两端各一个 120 Ω 终端电阻（对总线的特征阻抗匹配），中间挂接两台 GL40 驱动器与主控收发器，构成线性拓扑。
- **UART 段**：点对点直连，`/dev/serial0` 为树莓派主 UART；接收侧以 `timeout=0.1` 的非阻塞式逐字节读取实现流式同步（见 4.3、4.4 节）。

---

## 2. CAN 2.0B 核心机制深度解析

本章依据 **Bosch CAN Specification 2.0 (Part B, 1991)** 与 **ISO 11898-1:2015** 撰写。本系统全部电机报文运行于 CAN 2.0 **标准帧**（11-bit 标识符）模式。

### 2.1 帧类型总览与物理位时序

| 帧类型 | 用途 | 关键特征 | 本项目是否使用 |
| :--- | :--- | :--- | :--- |
| **数据帧 (Data Frame)** | 节点向网络广播数据 | RTR = 显性 0，含 0~8 字节数据段 | **是**（唯一使用的承载帧型：命令与遥测） |
| **遥控帧 (Remote Frame)** | 节点请求他节点发送指定 ID 的数据 | RTR = 隐性 1，无数据段，DLC 表示请求数据长度 | 否（GL40 主动回传遥测，无需远端请求） |
| **错误帧 (Error Frame)** | 节点检测到错误时破坏当前帧 | 主动错误标志：6 个显性位；被动错误标志：6 个隐性位；后随 8 位错误界定符 | 隐式发生（硬件自动处理） |
| **过载帧 (Overload Frame)** | 接收器来不及处理 / 间歇场检测到显性位 | 过载标志 6 个显性位 + 8 位过载界定符 | 隐式发生（硬件自动处理） |
| **帧间隔 (Interframe Space)** | 分隔相邻帧 | 3 个连续隐性位（间歇场）+ 可选挂起传送（被动错误节点补 8 个隐性位） | 帧与帧之间始终存在 |

### 2.2 标准数据帧完整位域结构 (SVG 矢量图)

以本项目实际使用的 **8 字节数据帧 (DLC = 8)** 为例，完整位域从 SOF 到 IFS 逐位列出：

| 位域 | 位长 | 电平约定 | 功能说明 |
| :--- | :---: | :--- | :--- |
| **SOF** | 1 | 显性 (0) | 帧起始，同时用于接收节点的硬同步 |
| **仲裁段 — Identifier** | 11 | — | 标识符，MSB 先行；决定报文优先级与接收滤波 |
| **仲裁段 — RTR** | 1 | 显性 (0)（数据帧） | 远程发送请求位；数据帧固定为显性 |
| **控制段 — IDE** | 1 | 显性 (0)（标准帧） | 标识符扩展位；标准帧固定显性 |
| **控制段 — r0** | 1 | 显性 (0) | 保留位，发送显性 |
| **控制段 — DLC** | 4 | — | 数据长度码，本系统所有报文固定 `0x8` |
| **数据段 Data[0..7]** | 64 | — | 8 字节有效负载（速度 float32 / 生命周期命令 / 遥测） |
| **CRC 序列** | 15 | — | CRC15 校验序列，生成多项式见 2.5 节 |
| **CRC 界定符** | 1 | 隐性 (1) | CRC 定界 |
| **ACK 槽** | 1 | 发送方发隐性，接收方回写显性 | 应答槽：**至少一个**正确接收的节点在此写入显性位 |
| **ACK 界定符** | 1 | 隐性 (1) | 应答定界 |
| **EOF** | 7 | 隐性 (1) × 7 | 帧结束标志 |
| **IFS（帧间空间）** | 3 | 隐性 (1) × 3 | 将下一帧与当前帧隔离，供控制器完成帧处理 |

**位长核算（8 字节数据帧）**：

$$
\underbrace{1}_{\text{SOF}} + \underbrace{11+1}_{\text{仲裁段}} + \underbrace{1+1+4}_{\text{控制段}} + \underbrace{64}_{\text{数据段}} + \underbrace{15+1}_{\text{CRC}} + \underbrace{2}_{\text{ACK}} + \underbrace{7}_{\text{EOF}} = 108 \; \text{bit}
$$

- 不含 IFS 的裸帧长 **108 bit**；计入 3 bit IFS 后为 **111 bit**。
- 位填充区覆盖 **SOF → CRC 序列**（共 $1+12+6+64+15 = 98$ bit），最坏情况额外插入填充位后单帧可达约 **130~135 bit**（详见 3.6 节负载率计算）。

> 本系统完整帧结构矢量图另见：`images/can_frame_phy_spec.svg`。

### 2.3 逐位非破坏性仲裁机制与竞争过程

#### 2.3.1 线与 (Wired-AND) 电平逻辑

ISO 11898-2 物理层定义两种总线电平：

| 电平状态 | CAN_H 与 CAN_L 压差 | 逻辑值 | 驱动方式 |
| :--- | :--- | :--- | :--- |
| **显性 (Dominant)** | 约 2 V 差分压差 | 0 | 收发器主动拉高 CAN_H、拉低 CAN_L（差分驱动） |
| **隐性 (Recessive)** | 约 0 V 差分压差 | 1 | 收发器呈高阻态，电平由终端电阻分压网络维持 |

多个节点同时驱动时，**显性 (0) 恒定覆盖隐性 (1)** —— 这构成"线与"特性：只要有一个节点输出显性，总线即为显性。

#### 2.3.2 仲裁规则

CAN 采用 **CSMA/CD+AMP（载波侦听多路访问 / 冲突检测 + 非破坏性逐位仲裁）**：

1. 总线空闲（检测到 11 个连续隐性位）时，任一节点均可发起发送。
2. 发送节点逐位发送标识符，同时**回读总线电平**。
3. 若发送隐性 (1) 而回读到显性 (0) → 判定**仲裁失败**，立即退出（不破坏正在进行的帧），转为接收，并在总线空闲后**自动重发**。
4. 若发送显性而回读显性 → 继续仲裁。
5. 结果：**标识符数值越小（前导显性位越多），优先级越高**；获胜节点无任何位流损失 —— 这就是"非破坏性"的含义。

#### 2.3.3 实例分析：0x201 (Yaw) vs 0x202 (Pitch)

假设极端情形下两台 GL40 的反馈帧同时在总线上竞争（11-bit 标识符逐位对比）：

```
Bit 位:      10  9  8  7  6  5  4  3  2  1  0
Yaw  0x201:   0  1  0  0  0  0  0  0  0  0  1
Pitch 0x202:  0  1  0  0  0  0  0  0  0  1  0
                                    ↑
                        Bit 1 首次出现分歧
```

| Bit 位 | 0x201 输出 | 0x202 输出 | 总线实际电平 | 仲裁结果 |
| :---: | :---: | :---: | :---: | :--- |
| Bit 10 ~ Bit 2 | 全部相同 | 全部相同 | 一致 | 双方均认为仲裁未分胜负 |
| Bit 1 | 隐性 (1) | **显性 (0)** | 显性 (0) | 0x202 回读显性 → 继续发送；0x201 发隐性读显性 → **仲裁失败退出** |
| Bit 0 | （退出，转入接收） | 显性→隐性序列 | — | **0x202 完整发出**，随后总线空闲，0x201 自动重发并胜出 |

结论与工程含义：

- **0x202 (513+1=514 < 513? 否：0x202=514 > 0x201=513)** —— 恰恰相反，**数值小的 0x201 优先级更高？验证：0x202 = 514，0x201 = 513**。逐位仲裁看的是**位串从 MSB 开始首个分歧位**：分歧发生在 **Bit 1**，该位 0x201 为 0（显性）、0x202 为 1（隐性），故**首个分歧位发显性的一方胜出，即 0x201 优先级高于 0x202**，与其数值更小完全一致。

> **勘误更正**：上表逐位推演中，Bit 1 处 0x201 的该位为 **显性 (0)**、0x202 为 **隐性 (1)**（0x201 二进制为 `010 0000 0001`，Bit 1 = 0；0x202 二进制为 `010 0000 0010`，Bit 1 = 1）。显性方 0x201 在 Bit 1 胜出，0x202 退避重发 —— 与"ID 数值越小优先级越高"的规则完全吻合（$0x201 = 513 < 0x202 = 514$）。以下为正确的仲裁推演表：

| Bit 位 | 0x201 输出 | 0x202 输出 | 总线实际电平 | 仲裁结果 |
| :---: | :---: | :---: | :---: | :--- |
| Bit 10 ~ Bit 2 | `0 1 0 0 0 0 0 0 0` | `0 1 0 0 0 0 0 0 0` | 一致 | 双方继续逐位仲裁 |
| **Bit 1** | **显性 (0)** | 隐性 (1) | 显性 (0) | 0x201 正常回读；0x202 发隐性读显性 → **仲裁失败，立即退避** |
| Bit 0 | 显性 (1) | （已转接收） | 显性 | **0x201 完整发出**；0x202 在总线空闲后自动重发 |

- **本项目的实际情况**：`0x201` 与 `0x202` 均由**同一 Master（树莓派）串行发出**（中间隔 5 ms 软件延时，见 6 章），两帧**永远不会同时在总线上竞争**，仲裁机制实际处于"零冲突"工作状态。上表推演仅用于说明多节点并发场景下的优先级语义，并为未来系统扩展（如新增节点）提供规划依据：ID 数值越小（显性位越靠前）的报文优先级越高，**命令类报文应分配低 ID，遥测类报文可分配相对较高的 ID**。

### 2.4 位填充 (Bit Stuffing) 与最坏帧长推导

#### 2.4.1 规则定义

为保证接收节点在**每个位边界**都有足够陡峭的信号沿用于重同步（Re-synchronization），CAN 规定：

- 发送器在 **SOF 到 CRC 序列之间**（即全部"需要接收器重同步的动态位流"区域），每当**连续 5 个同极性位**出现后，**自动插入 1 个极性相反的位**（反码填充位）。
- 接收器按同一规则**删除填充位**，恢复原始位流。
- **不参与填充的区域**：CRC 界定符、ACK 槽、ACK 界定符、EOF、IFS —— 这些是**固定形式位场**（位型固定，不需要沿密度保障），填充计数器在此区间不计数；这也是错误检测中"固定形式位检查"的依据（见 2.5 节）。

#### 2.4.2 填充位计数与帧长影响

- 填充区理论长度上限：98 bit（8 字节数据帧，SOF → CRC 序列）。
- 最坏填充比：每 4 个原始位插入 1 个填充位 → 理论最大填充数 $\lceil (98-4)/4 \rceil = 24$ bit。
- 对帧长的影响谱系：

```
 无填充裸帧(不含IFS)      含填充典型值              最坏情况
 108 bit  ─────────────►  约115~125 bit ────────►  135 bit
 (111 bit 含 IFS)          (本规范规划取 130 bit)    (111+24, 含IFS)
```

- **数据相关性**：载荷全 0（如 `0x00000000` 停转帧）或全 1（如生命周期命令 `FF×7`）时填充次数显著增多；float32 速度值则视尾数随机性而定。3.6 节的负载率计算保守地按 130 bit/帧规划。

### 2.5 差错校验机制与 CRC15 生成多项式

CAN 帧内含 **三重相互独立的检错手段**，任一失守均可被另一重兜底：

| 机制 | 检测位置 | 原理 | 漏检特性 |
| :--- | :--- | :--- | :--- |
| **① CRC15 循环冗余校验** | 数据段 + CRC 序列 | 生成多项式 $G(x) = x^{15}+x^{11}+x^{10}+x^{9}+x^{8}+x^{7}+x^{6}+x^{4}+x^{3}+x^{1}+x^{0}$（十六进制系数 `0x4599`），对 SOF 起至数据段止的位流做除法，余数即 15 位 CRC 序列 | 全部 ≤15 位突发错误；98% 以上更长突发（汉明距离 6） |
| **② ACK 应答机制** | ACK 槽 | 发送方在 ACK 槽发隐性并**回读**；**至少一个**正确完成 CRC 校验的接收节点回写显性位。发送方回读到显性 → 确认有节点正确收到；回读隐性 → 触发 **ACK 错误**并重发 | 保证"至少一个节点正确接收"才宣告成功（但无法定位具体节点） |
| **③ 格式 / 固定形式位检查** | 全帧 | 检查固定电平位：SOF 必须显性、IDE/r0 显性、CRC 界定符与 ACK 界定符必须隐性、EOF 必须 7 连续隐性、DLC ≤ 8、填充规则（连续 6 个同极性位在填充区非法）等 | 捕获协议级异常与控制器失步 |

**错误帧响应流程**：任一节点检测到上述任一错误 → 立即中断当前帧 → 发送错误标志（6 位，见 2.6 节）破坏帧 → 当前帧被所有节点丢弃 → 发送方**自动重发**原帧（无需软件介入）。

### 2.6 错误界定与节点故障隔离状态机 (TEC/REC)

CAN 协议最具工程价值的机制之一是**故障隔离 (Fault Confinement)**：每个控制器维护两个递增计数器 —— **TEC (Transmit Error Counter)** 与 **REC (Receive Error Counter)**，据此将节点划分为三种状态，使故障节点"自动降级、最终自动离线"，防止单一故障节点瘫痪整条总线。

#### 2.6.1 TEC/REC 计数规则（核心条目）

| 编号 | 触发事件 | 计数器动作 |
| :---: | :--- | :--- |
| R1 | 接收节点检测到错误（发送主动错误标志 / 过载标志期间除外） | REC + 1 |
| R2 | 接收节点发送错误标志后的第一位检测到显性位 | REC + 8 |
| T1 | 发送节点发送错误标志（例外：被动错误节点因 ACK 槽无显性位而检错且自身被动错误标志期间无显性位 → TEC 不变） | TEC + 8 |
| T2 | 发送节点在发送主动错误标志 / 过载标志期间检测到位错误 (Bit Error) | TEC + 8 |
| T3 | 发送节点在发送被动错误标志期间检测到位错误 | TEC + 7 |
| S1 | 一帧成功发送（无错误直至 EOF） | TEC − 1（下限 0） |
| S2 | 一帧成功接收（直至 ACK 槽正确回写） | REC − 1（REC ∈ [1,127]）；若 REC > 127，成功接收后 REC 置为 120~127 区间 |

#### 2.6.2 三种错误状态与转换条件

```mermaid
stateDiagram-v2
    [*] --> ErrorActive : 上电初始化<br/>TEC=0, REC=0
    ErrorActive --> ErrorPassive : TEC > 127 或 REC > 127
    ErrorPassive --> ErrorActive : 成功发送/接收使计数器<br/>回落至 TEC≤127 且 REC≤127
    ErrorPassive --> BusOff : TEC > 255
    BusOff --> ErrorActive : 检测到 128 次<br/>11 个连续隐性位<br/>TEC/REC 清零
    ErrorActive : ERROR ACTIVE (错误激活)
    ErrorActive : 正常通信；检出错误时发 6 个显性位<br/>(主动错误标志)，主动破坏坏帧
    ErrorPassive : ERROR PASSIVE (错误被动)
    ErrorPassive : 只发 6 个隐性位 (被动错误标志)<br/>帧后附加 8 位挂起传送；不再干扰正常帧
    BusOff : BUS OFF (总线关闭)
    BusOff : 收发器输出置隐性、脱离总线<br/>不发送、不接收、不应答
```

| 状态 | 进入条件 | 行为特征 | 恢复路径 |
| :--- | :--- | :--- | :--- |
| **Error Active** | TEC ≤ 127 且 REC ≤ 127 | 可正常收发；检出错误发**主动错误标志**（6 显性位），立即破坏总线上的坏帧 | —（正常态） |
| **Error Passive** | TEC > 127 或 REC > 127 | 检出错误仅发**被动错误标志**（6 隐性位，不覆盖总线电平）；发送后须插入 8 位**挂起传送 (Suspend Transmission)**；ACK 错误不再加重 TEC | 成功收发使 TEC/REC 降至 ≤ 127 |
| **Bus Off** | TEC > 255 | **与总线完全断开**：输出恒为隐性，不发送、不接收、不应答任何报文 | 硬件监视总线，**连续检测到 128 次"11 个隐性位"序列**（即 128 次总线空闲判定）后，TEC/REC 清零，节点回到 Error Active 并重新参与通信 |

> [!TIP]
> **总线脱扣自愈机制 (Bus-Off Recovery)**
> 硬件错误计数器与总线关闭状态机提供了关键的链路韧性：
> - **瞬态故障自愈**：当偶发线缆抖动导致丢包时，节点监听 128 次空闲序列即可自动重连，无需人工介入重启；
> - **硬性故障隔离**：当单机物理损坏持续发错时，硬件强行脱机断开，保护总线其余节点不被广播风暴淹没。

### 2.7 1Mbps 位时序与采样点参数计算

#### 2.7.1 位时序四段模型

CAN 将一个标称位时间 (NBT) 划分为四个由 **Tq (Time Quantum)** 组成的时段：

```
 |◄───────────── 1 位时间 NBT (1 Mbps 下 = 1000 ns) ─────────────►|
 | Sync_Seg | Prop_Seg |      Phase_Seg1      |   Phase_Seg2    |
 |◄─ 1 Tq ─►|◄─ N Tq ─►|◄─────── M Tq ───────►|◄──── K Tq ─────►|
                                      ↑
                                  采样点 SP
 |◄────────── 写入/仲裁判定窗 ─────────────►|◄─ 采样后缓冲 ─►|
```

| 时段 | 作用 | 可编程范围 |
| :--- | :--- | :--- |
| **Sync_Seg** | 期望位跳变沿落在该段内；硬件据此做**硬同步** | 固定 1 Tq |
| **Prop_Seg** | 补偿网络物理延时（收发器延迟 + 电缆传播，约 5 ns/m + 器件 100~250 ns） | 1~8 Tq（控制器相关） |
| **Phase_Seg1 (PS1)** | 采样前的重同步缓冲；延迟重同步可将其拉长 | 1~8 Tq |
| **Phase_Seg2 (PS2)** | 采样后的重同步缓冲；须 ≥ 信息处理时间 IPT（CAN 2.0 规定 IPT = 2 Tq） | 1~8 Tq，且 ≥ 2 Tq |
| **SJW** | 重同步跳转宽度，限制每次重同步的最大修正量 | ≤ min(4 Tq, PS2) |

#### 2.7.2 1 Mbps 下的示例配置

$$
\text{波特率} = \frac{f_{clk}}{\text{BRP} \times \text{NBT}_{Tq}} = 1\,\text{Mbps}, \qquad \text{NBT} = 1000\,\text{ns}, \qquad T_q = \frac{\text{NBT}}{\text{Tq 数/位}}
$$

| 参数 | 示例取值 (NBT = 16 Tq) | 说明 |
| :--- | :---: | :--- |
| Tq | 62.5 ns | 要求控制器输入时钟 ≥ 16 MHz |
| Sync_Seg | 1 Tq | 固定 |
| Prop_Seg | 7 Tq | 覆盖长线缆 + 两级收发器延时 |
| Phase_Seg1 | 6 Tq | 采样前缓冲 |
| Phase_Seg2 | 2 Tq | 满足 IPT ≥ 2 Tq 下限 |
| **采样点 SP** | $(1+7+6)/16 = 87.5\%$ | 与 CiA 推荐值一致 |
| SJW | 2 Tq | 晶振容差兜底 |

> [!IMPORTANT]
> **采样点配置一致性原则**
> 在多节点现场总线网络中，所有挂载设备的采样点必须调谐一致（工业惯例推荐 $75.0\% \sim 87.5\%$）。
> 若主控与电机驱动器的采样时段划分不一致，长线缆传输中的累积相移极易引发零星位错误与偶发丢帧。

---

## 3. CubeMars GL40 应用协议全析

来源依据：`【协议手册】GL40模组驱动使用说明.pdf`（CubeMars 官方驱动器通信规范 **V1.0.0**，2024-07-18）。

### 3.1 11-Bit ID 编址规则与三种控制模式

GL40 采用 CAN 2.0 标准 11 位帧 ID，**高 3 位 (bits[10:8]) 定义控制模式，低 8 位 (bits[7:0]) 定义驱动器节点 ID**：

$$
\text{Arbitration ID} = (\text{Mode} \ll 8) \;|\; \text{Node ID}
$$

```text
 10   9   8   7   6   5   4   3   2   1   0   (Bit 位)
+--------------+--------------------------------+
| Mode (3 bit) |        Node ID (8 bit)         |
+--------------+--------------------------------+
  bits[10:8]          bits[7:0]
```

| 控制模式 | Mode 编码 (bits[10:8]) | ID 基址 | 数据负载构成 | 本项目使用 |
| :--- | :---: | :---: | :--- | :---: |
| **MIT 运控模式** | `0b000` | `0x000` | 位置 / 速度 / Kp / Kd / 前馈力矩多参数位打包（位域定义以手册 V1.0.0 为准） | 否 |
| **位置速度模式** | `0b001` | `0x100` | 目标位置 + 目标速度双参数打包（位域定义以手册为准） | 否 |
| **速度模式 (Mode 2)** | `0b010` | `0x200` | **Data[0:4] = float32 小端速度 (rad/s)，Data[4:8] = `0x00` 填充** | **是** |

本项目源码 `gimbal_can.py` 中的编址实例：

- **Yaw 偏航轴**：`0x201` = (Mode 2 ≪ 8) | 0x01 → **速度模式，Node ID = 1**
- **Pitch 俯仰轴**：`0x202` = (Mode 2 ≪ 8) | 0x02 → **速度模式，Node ID = 2**

报文速查表（方向：主控 → 驱动器，均 `is_extended_id=False`，DLC = 8）：

| 功能 | 发送 ID | 负载 (Bytes 0~7) |
| :--- | :---: | :--- |
| Yaw 速度指令 | `0x201` | `<vel_f32_LE> 00 00 00 00` |
| Pitch 速度指令 | `0x202` | `<vel_f32_LE> 00 00 00 00` |
| Yaw / Pitch 生命周期命令 | `0x201` / `0x202` | 见 3.2 节命令集 |
| 驱动器遥测反馈（从机 → 主控） | `0x000` (Master ID) | 见 3.4 节反馈帧结构 |

### 3.2 电机生命周期控制命令集 (DLC = 8)

电机的运行使能、安全失能、机械零点自标定与故障复位通过专用 8 字节报文执行（前 7 字节全 `0xFF`，末字节为命令码）：

| 指令功能 | 命令码 | 十六进制报文负载 (Bytes 0 ~ 7) | 源码函数封装 | 驱动器底层响应 |
| :--- | :---: | :--- | :--- | :--- |
| **使能 (进入电机运行模式)** | `FC` | `FF FF FF FF FF FF FF FC` | `gimbal.enable()` | 开启逆变桥 PWM，电机进入 FOC 矢量伺服锁定态 |
| **失能 (退出电机运行模式)** | `FD` | `FF FF FF FF FF FF FF FD` | `gimbal.disable()` | 释放相线 PWM 输出，转子进入自由空载态 |
| **设置当前位置为机械零点** | `FE` | `FF FF FF FF FF FF FF FE` | —（本项目未封装） | 将当前编码器多圈绝对位置写为坐标原点 ($0.0\ \text{rad}$) |
| **清除驱动器系统错误标志** | `FB` | `FF FF FF FF FF FF FF FB` | —（本项目未封装） | 清除过流 (OCP)、欠压 (UVLO)、通讯超时等硬件告警锁止 |

源码中的命令时序（`gimbal_can.py` 实测行为）：

```python
def enable(self):                 # 使能：Yaw → 20ms → Pitch
    self.send(self.yaw_id, self.enable_cmd)
    time.sleep(0.02)              # 20 ms 轴间间隔
    self.send(self.pitch_id, self.enable_cmd)

def disable(self):                # 失能：先速度归零 → 50ms → Yaw失能 → 20ms → Pitch失能
    self.stop()                   # send_speed(0.0, 0.0)，内部自带 5ms 轴间隔
    time.sleep(0.05)
    self.send(self.yaw_id, self.disable_cmd)
    time.sleep(0.02)
    self.send(self.pitch_id, self.disable_cmd)
```

**时序设计依据**：先零速再失能，避免机械在高速旋转瞬间断电产生冲击；20~50 ms 的轴间/阶段间隔确保每个命令帧都被驱动器完整接收并处理（命令处理耗时 + CAN 帧自动重发裕量）。

### 3.3 模式 2 速度控制帧封装与 IEEE-754 浮点手算推导

#### 3.3.1 帧封装规则

速度模式下数据段（DLC = 8）布局：

| 字节 | 内容 | 说明 |
| :---: | :--- | :--- |
| `Data[0..3]` | 目标角速度，**IEEE-754 float32，小端序** | 单位 **rad/s**，正负号即转向 |
| `Data[4..7]` | `00 00 00 00` | 保留填充字段 |

源码实现（`gimbal_can.py`，逐字对应）：

```python
def pack_speed(self, vel):
    # 速度模式：8字节中只用前4字节float，小端
    return struct.pack("<f", float(vel)) + bytes([0x00, 0x00, 0x00, 0x00])
```

#### 3.3.2 IEEE-754 float32 编码格式回顾

float32 共 32 位：1 位符号 S + 8 位阶码 E（偏置 127）+ 23 位尾数 M（隐含前导 1）：

$$
V = (-1)^{S} \times \left(1 + \frac{M}{2^{23}}\right) \times 2^{E-127}, \qquad E = \lfloor \log_2 |V| \rfloor + 127
$$

#### 3.3.3 精确编码实例：0.1 rad/s 的手算推导

**第一步 — 规格化**：$0.1 = 1.6 \times 2^{-4}$ → 符号位 $S = 0$，指数 $E = -4 + 127 = 123 = \texttt{0b01111011}$。

**第二步 — 尾数求解**（$0.6$ 的二进制转换，×2 取整法循环）：

```
0.6 × 2 = 1.2 → 取 1   ┐
0.2 × 2 = 0.4 → 取 0   │
0.4 × 2 = 0.8 → 取 0   ├─ "1001" 四位一循环
0.8 × 2 = 1.6 → 取 1   ┘
⇒ 0.6 = 0.1001 1001 1001 ... (1001 循环)
⇒ 尾数前 23 位: 10011001100110011001100 | 第24位=1, 后续非全零
⇒ 就近舍入进位 ⇒ M = 10011001100110011001101
```

**第三步 — 拼接与字节序**：

```
S  E (8bit)   M (23bit)
0  01111011   10011001100110011001101
→ 0011 1101 1100 1100 1100 1100 1100 1101
→ 0x3DCCCCCD  (大端书写序)
```

$$
\underbrace{\texttt{3D}}_{\texttt{S+E 高位}} \underbrace{\texttt{CC}}_{\texttt{M 高16位}} \underbrace{\texttt{CC}}_{\texttt{}} \underbrace{\texttt{CD}}_{\texttt{M 低位}}
\;\xrightarrow{\text{小端序反转}}\;
\texttt{CD CC CC 3D}
$$

**第四步 — 组帧**：`Data[0..3] = CD CC CC 3D`，`Data[4..7] = 00 00 00 00`，
完整帧：`0x201 [8] CD CC CC 3D 00 00 00 00`。

#### 3.3.4 五组速度值的完整编码对照表

| 速度 (rad/s) | 符号 S | 指数 E（偏置后） | 尾数 M（23 bit） | float32 十六进制 | **小端字节流 (Data[0..3])** |
| :---: | :---: | :---: | :--- | :---: | :--- |
| `0.0` | 0 | `00000000` | `00000000000000000000000` | `0x00000000` | `00 00 00 00` |
| `0.05` | 0 | `01111010` (122, $2^{-5}$) | `10011001100110011001101` | `0x3D4CCCCD` | `CD CC 4C 3D` |
| `0.1` | 0 | `01111011` (123, $2^{-4}$) | `10011001100110011001101` | `0x3DCCCCCD` | `CD CC CC 3D` |
| `-0.3` | 1 | `01111101` (125, $2^{-2}$) | `00110011001100110011010` | `0xBE99999A` | `9A 99 99 BE` |
| `1.0` | 0 | `01111111` (127, $2^{0}$) | `00000000000000000000000` | `0x3F800000` | `00 00 80 3F` |

推导附注：

- `0.05` 与 `0.1` 尾数完全相同（都是 $1.6$ 的尾数），仅阶码差 1（$2^{-5}$ vs $2^{-4}$）。
- `-0.3`：$0.3 = 1.2 \times 2^{-2}$，$0.2 = 0.\overline{0011}_2$，尾数第 24 位为 1 触发进位舍入；符号位独立置 1，其余位与 $+0.3$ 完全一致。
- `0.0`：IEEE-754 定义零为全零位型，**符号位为 0 的 +0.0** 是精确值（无舍入误差），这也是源码 `stop()` 发送 `send_speed(0.0, 0.0)` 停转可靠的原因。
- float32 的舍入误差量级为 $2^{-23} \approx 1.19 \times 10^{-7}$ 相对精度，远小于 GL40 **0.1°（约 0.00175 rad）** 的控制精度指标，编码误差可忽略。

### 3.4 驱动器反馈遥测帧 (Feedback Packet) 与 12-bit 解包公式

GL40 驱动器收到控制指令或按配置周期主动上报时，回传 8 字节遥测反馈帧，**目标 ID 为 Master ID `0x000`**：

```text
GL40 驱动器 8 字节反馈遥测帧 (Feedback Packet):
+----------+----------+----------+----------+----------+----------+----------+----------+
|  Byte 0  |  Byte 1  |  Byte 2  |  Byte 3  |  Byte 4  |  Byte 5  |  Byte 6  |  Byte 7  |
+----------+----------+----------+----------+----------+----------+----------+----------+
| ERR | ID | Position (16-bit)   | Velocity (12-bit)  | Torque (12-bit)   | T_driver | T_motor  |
+----------+---------------------+--------------------+-------------------+----------+----------+
  \    /
 [7:4] 故障码 ERR:
       0x0: 正常无故障失能态      0x1: 正常使能态          0x8: 总线超压 (Over-Voltage)
       0x9: 总线欠压 (UVLO)      0xA: 相线过流 (OCP)      0xB: MOS 管过温 (>100℃)
       0xC: 线圈过温 (>120℃)     0xD: CAN 帧通讯丢失      0xE: 驱动器过载堵转
```

#### 3.4.1 位域解包公式

| 字段 | 字节 | 原始码提取公式 | 说明 |
| :--- | :--- | :--- | :--- |
| **ERR 故障码** | `Data[0]` 高 4 位 | $ERR = \text{Data[0]} \gg 4$ | 见上方 ERR 码表 |
| **节点 ID** | `Data[0]` 低 4 位 | $ID = \text{Data[0]} \,\&\, \texttt{0x0F}$ | 与目标帧 Node ID 对应（1 = Yaw，2 = Pitch） |
| **位置** | `Data[1..2]` | $raw_p = (\text{Data[1]} \ll 8)\, |\, \text{Data[2]}$ | 16-bit 定点打包，物理量纲换算系数以手册 V1.0.0 定义为准 |
| **速度** | `Data[3..4]` | $raw_v = (\text{Data[3]} \ll 4)\, |\, (\text{Data[4]} \gg 4)$ | **12-bit** 跨字节打包：Byte 3 全 8 位 + Byte 4 高 4 位 |
| **扭矩** | `Data[4..5]` | $raw_t = ((\text{Data[4]} \,\&\, \texttt{0x0F}) \ll 8)\, |\, \text{Data[5]}$ | **12-bit** 跨字节打包：Byte 4 低 4 位 + Byte 5 全 8 位 |
| **驱动器温度** | `Data[6]` | $\text{int8}$ 直读 | 单位 ℃（对照 ERR `0xB` MOS 过温 >100 ℃ 门限） |
| **电机温度** | `Data[7]` | $\text{int8}$ 直读 | 单位 ℃（对照 ERR `0xC` 线圈过温 >120 ℃ 门限） |

12-bit 速度 / 扭矩解包的位级示意：

```
  Byte 3           Byte 4           Byte 5
+--------+       +--------+       +--------+
|vvvvvvvv|       |vvvv|tttt|       |tttttttt|
+--------+       +--------+       +--------+
  \_8bit_/  \_4bit_/  \_4bit_/  \__8bit__/
   Velocity  Velocity   Torque    Torque
     [11:4]    [3:0]     [11:8]     [7:0]
```

> **实现现状说明**：当前源码 `gimbal_can.py` 为**单向发送型**驱动封装，未挂接 RX 回调消费反馈帧（总线上的 `0x000` 反馈帧仅由 `candump` 等调试工具观察）。上述解包公式为协议规范定义，供后续闭环反馈功能扩展时直接引用；物理量纲换算系数请对照 CubeMars 手册 V1.0.0 原文，本规范不做推测性数值。

### 3.5 GL40 驱动器电气规格速查表

| 参数 | 规格 |
| :--- | :--- |
| 额定工作电压 | **24 V**（工作范围 **8 ~ 32 V**） |
| 额定电流 | **2 A** |
| 峰值电流 | **10 A** |
| 待机电流 | **≤ 50 mA** |
| 外形尺寸 | **41 × 38 mm** |
| 控制精度 | **0.1°** |
| 控制算法 | **FOC 磁场定向控制 + 自抗扰控制 (ADRC)** |
| 电源接口 | **XT30 (2+2) PW-M** |
| 调试串口 | **GH1.25-3P**（另有串口控制通道，本系统未启用） |
| 备用控制方式 | **PWM 输入：50 Hz，有效脉宽 800 ~ 2200 μs**（与 CAN 并存时 **CAN 优先**，见 3.7 节） |

### 3.6 总线负载率与吞吐裕量分析

#### 3.6.1 单帧位长核算

综合 2.2 节（裸帧 108 bit / 含 IFS 111 bit）与 2.4 节（填充区 98 bit，最坏 +24 bit）：

| 情形 | 单帧位长 (含 IFS) | @1Mbps 发送耗时 |
| :--- | :---: | :---: |
| 无填充 | 111 bit | 111 μs |
| 典型平均（填充少量） | 约 115 ~ 125 bit | 115 ~ 125 μs |
| **保守规划值** | **约 130 bit** | **130 μs** |
| 理论最坏 | 135 bit | 135 μs |

#### 3.6.2 50 Hz 控制周期下的总线占用

控制环以 **50 Hz（周期 T = 20 ms）** 运行，每周期经 `send_speed` 下发两帧速度指令（`0x201` 与 `0x202`）：

$$
\text{下行负载} = 50\,\text{Hz} \times 2\,\text{帧} \times 130\,\text{bit} = 13{,}000\,\text{bit/s} = 13\,\text{kbps}
$$

$$
\text{占用率} = \frac{13\,\text{kbps}}{1000\,\text{kbps}} = 1.3\%
$$

若驱动器按指令应答方式回传遥测帧（每条指令触发一帧 `0x000` 反馈，具体上报模式以手册配置为准），最坏再叠加等量上行负载：

| 负载项 | 帧率 | 帧长 | 码率 | 占 1Mbps |
| :--- | :---: | :---: | :---: | :---: |
| 下行控制帧（本系统实际） | 100 帧/s | 130 bit | 13 kbps | **1.3%** |
| 上行反馈帧（若启用指令应答） | ~100 帧/s | 130 bit | ~13 kbps | ~1.3% |
| **合计最坏** | — | — | **~26 kbps** | **~2.6%** |

```
1Mbps CAN 总线物理带宽分配与空闲裕量 (标称总带宽: 1,000 kbps):
[██ 1.3% 下行控制][██ 1.3% 上行反馈][░░░░░░░░░░░░░░░░░░░░░░░░░░░░░░░░░░░░░ 97.4% 剩余空闲安全裕量]
```

```mermaid
flowchart LR
    subgraph BUS["1Mbps CAN 物理总线带宽构成 (1,000 kbps 总吞吐量)"]
        direction LR
        DOWN["下行控制帧<br/>13 kbps (1.3%)"]
        UP["上行反馈帧 (若启用)<br/>~13 kbps (1.3%)"]
        IDLE["物理总线空闲安全裕量<br/>~974 kbps (97.4%)"]

        DOWN --- UP --- IDLE
    end
    classDef downCls fill:#1e40af,stroke:#3b82f6,stroke-width:1.5px,color:#ffffff;
    classDef upCls fill:#6b21a8,stroke:#a855f7,stroke-width:1.5px,color:#ffffff;
    classDef idleCls fill:#065f46,stroke:#10b981,stroke-width:1.5px,color:#ffffff;
    classDef busCls fill:#0f172a,stroke:#334155,stroke-width:1.5px,color:#f8fafc;
    class DOWN downCls;
    class UP upCls;
    class IDLE idleCls;
    class BUS busCls;
```

**裕量结论**：按 CAN 网络工程惯例，**峰值负载宜控制在 60~80% 以下**以保障最坏情况下的仲裁退避与时延确定性。本系统合计约 2.6% 的占用率留有 **>97% 裕量**，即使叠加调试工具（`candump` 不发帧）、未来扩展节点（多轴扩展、IK 运动指令）也远在安全域内；5 ms 轴间延时（第 6 章）在此负载下属于"充裕冗余"而非必需约束。

### 3.7 PWM 输入模式与 CAN 模式对比

GL40 除 CAN 外还支持 PWM 脉宽输入控制（本系统未启用）：

| 对比维度 | PWM 输入模式 | CAN 模式（本系统采用） |
| :--- | :--- | :--- |
| 物理接口 | 单路 PWM 信号线 | 差分双绞线（ISO 11898-2） |
| 信号形式 | **50 Hz 周期，有效脉宽 800 ~ 2200 μs** | 1 Mbps 数字报文 |
| 控制粒度 | 脉宽比例映射（模拟量级） | float32 精确速度值（rad/s） |
| 多轴扩展 | 每轴一路独立信号线 | 单总线多节点寻址（Node ID） |
| 反馈遥测能力 | 无 | 8 字节反馈帧（位置/速度/扭矩/温度/故障码） |
| 错误检测 | 无（信号丢失检测依赖驱动器超时） | CRC15 + ACK + 错误界定三重机制 |
| **优先级仲裁** | 低 | **高 —— 当 PWM 与 CAN 同时接入时，CAN 指令优先生效** |

> **规范说明**：由于系统接入了 CAN，即便硬件上存在 PWM 信号（如调试期间误接线），驱动器也以 CAN 报文为准，这一"CAN 优先"规则避免了双控制源竞态。

---

## 4. 北醒 TFmini Plus UART 串行测距协议全析

TFmini Plus 激光测距传感器（ToF 原理）通过 TTL 串口输出标准 9 字节定长二进制数据包，参数 **115200 bps / 8-N-1**，输出帧率 **100 Hz**。传感器指标：量程 **0.1 ~ 12 m**，盲区 **10 cm**。

### 4.1 9 字节定长二进制数据包布局映射表

| 字节偏移 | 字段名称 | 类型 | 说明与物理量解析公式 |
| :---: | :--- | :---: | :--- |
| `Byte 0` | 帧头标志 1 | `uint8` | 固定为 `0x59` ('Y') |
| `Byte 1` | 帧头标志 2 | `uint8` | 固定为 `0x59` ('Y') |
| `Byte 2` | 距离低字节 (`Dist_L`) | `uint8` | $\text{Distance} = \text{Dist\_L} + (\text{Dist\_H} \ll 8)$，单位：$\text{cm}$ |
| `Byte 3` | 距离高字节 (`Dist_H`) | `uint8` | 有效量程 10 ~ 1200 cm（0.1 ~ 12 m，盲区 10 cm 内输出无效） |
| `Byte 4` | 信号强度低字节 (`Str_L`) | `uint8` | $\text{Strength} = \text{Str\_L} + (\text{Str\_H} \ll 8)$ |
| `Byte 5` | 信号强度高字节 (`Str_H`) | `uint8` | 反射光强度，0 ~ 65535；`0xFFFF` 表示光学饱和无效值 |
| `Byte 6` | 内部温度低字节 (`Temp_L`) | `uint8` | $\text{Temp} = (\text{Temp\_L} + (\text{Temp\_H} \ll 8)) / 8 - 256$（℃） |
| `Byte 7` | 内部温度高字节 (`Temp_H`) | `uint8` | 芯片内部温度监控（源码未显式读取，见 4.5 节） |
| `Byte 8` | 累加校验和 (`Checksum`) | `uint8` | 前 8 字节累加和低 8 位：$\left(\sum_{i=0}^{7} \text{Byte}[i]\right) \bmod 256$ |

### 4.2 校验和算法数学定义与抗误码分析

#### 4.2.1 数学定义

设帧字节序列为 $B_0, B_1, \ldots, B_8$，则发送端校验和定义为模 $2^8$ 累加：

$$
C_{tx} = \left(\sum_{i=0}^{7} B_i\right) \bmod 2^{8}, \qquad B_8 \equiv C_{tx}
$$

接收端判定（源码 `tfmini_uart.py` 逐字对应）：

```python
checksum = sum(frame[0:8]) & 0xFF   # 等价于 ΣB[0..7] mod 256
if checksum != frame[8]:
    return None                      # 校验失败 → 丢弃整帧，重新同步
```

#### 4.2.2 抗误码能力分析

设传输中第 $i$ 字节发生差错 $\delta_i$（实际值 − 期望值，mod 256 意义下），则**漏检充要条件**为：

$$
\sum_{i=0}^{8} \delta_i \equiv 0 \pmod{256}
$$

| 差错模式 | 漏检概率 | 分析 |
| :--- | :---: | :--- |
| **任意单字节、单比特错误** | **0%（必检）** | 单比特翻转 $\delta = \pm 2^k,\ k \in [0,7]$，不可能为 0 (mod 256) |
| **任意单字节任意多比特错误** | 0%（必检） | $\delta \neq 0$ 且无其他字节补偿 → 必检出 |
| 双字节互补差错（$\delta_1 = -\delta_2$） | 漏检 | 例：两字节各错 `+1` 与 `−1`，和为 0 → 漏检 |
| **随机 n 比特错误（统计平均）** | $\approx 1/256 \approx 0.39\%$ | 差错向量和落入 256 个余数类中"0 类"的概率 |

**工程结论**：累加校验和以 **1 字节开销** 实现"单比特必检、平均检出率 99.6%"。对于 115200 bps 短距板内 TTL 链路（误码率典型 $<10^{-6}$）而言，残余漏检率低于 $4 \times 10^{-9}$/帧，且漏检帧还须通过 4.3 节的物理门限三重过滤才能污染下游数据——多层防御下，距离数据完整性的置信度满足跟踪云台的传感要求。（若需更强保障，可升级 CRC-16 类方案，但需传感器固件支持，非本型号协议范畴。）

### 4.3 双 0x59 滑动窗口帧同步 FSM 状态机 (Mermaid)

源码 `tfmini_uart.py` 中的 `_read_frame` 基于逐字节滑动窗口与严格数据有效性检验实现帧同步。细化后的状态机（标注源码行为与超时语义）：

```mermaid
flowchart TD
    S0(["WAIT_HEADER_1<br/>b = ser.read(1)，timeout=0.1s"]) -->|"b != 0x59<br/>杂散字节直接丢弃"| S0
    S0 -->|"b == 0x59<br/>命中帧头第 1 字节"| S1(["WAIT_HEADER_2<br/>b2 = ser.read(1)"])

    S1 -->|"b2 != 0x59<br/>伪帧头，回到重扫<br/>(注: 该字节不回溯, 见下方边界分析)"| S0
    S1 -->|"b2 == 0x59<br/>双帧头锁定"| S2(["READ_PAYLOAD_7B<br/>frame = b + b2 + ser.read(7)"])

    S2 -->|"len(frame) != 9<br/>半包/串口超时 → 整帧作废"| S0
    S2 -->|"len(frame) == 9<br/>定长帧收齐"| S3(["CHECKSUM_VALIDATE"])

    S3 -->|"sum(frame[0:8]) & 0xFF != frame[8]<br/>校验和错误 → 丢弃"| S0
    S3 -->|"校验和通过"| S4(["PHYSICAL_FILTER<br/>三重门限"])

    S4 -->|"strength <= 100<br/>弱反射/虚警"| S0
    S4 -->|"strength == 65535<br/>接收管光学饱和"| S0
    S4 -->|"distance == 0<br/>盲区遮挡/无效零点"| S0
    S4 -->|"三重门限全部通过"| S5(["UPDATE_SHARED_MEMORY<br/>threading.Lock 临界区写入<br/>self.distance / self.strength"])

    S5 -->|"写锁释放, 回到继续采流"| S0
```

对应源码核心段（`tfmini_uart.py`）：

```python
def _read_frame(self, ser):
    while self.running:
        b = ser.read(1)
        if b != b"\x59":
            continue
        b2 = ser.read(1)
        if b2 != b"\x59":
            continue
        frame = b + b2 + ser.read(7)
        if len(frame) != 9:
            return None
        checksum = sum(frame[0:8]) & 0xFF
        if checksum != frame[8]:
            return None
        distance = frame[2] + (frame[3] << 8)
        strength = frame[4] + (frame[5] << 8)
        valid = strength > 100 and strength != 65535 and distance != 0
        if not valid:
            return None
        return distance, strength
```

**边界情形分析（残余风险声明）**：

- **三连 `0x59` 序列**（`59 59 59 ...`）：FSM 消费前两个 `0x59` 作为帧头后，若后续 7 字节校验失败，整帧作废回到 S0 —— 而真实帧可能恰从**第二个** `0x59` 开始，该字节已被消费且**无回溯机制**，导致这一帧丢失。由于丢失帧会被下一个 10 ms 帧周期自然补齐（100 Hz 高冗余），且校验和 + 门限过滤保证了"宁可丢帧、不进错数"的设计取向，该残余风险在工程上可接受。
- **统计意义**：随机字节流中双 `0x59` 伪头概率为 $2^{-16} \approx 1.5 \times 10^{-5}$/位置，再叠加校验和通过概率（误码场景下约 $2^{-8}$），伪帧进入物理过滤层的概率可忽略。

### 4.4 字节流粘包半包处理策略与超时语义

`pyserial` 提供的是**无消息边界的字节流**，协议层必须自行解决三个经典问题：

| 问题 | 现象 | 本实现的应对机制 |
| :--- | :--- | :--- |
| **粘包 (Coalescing)** | 内核接收缓冲区可能一次积压多帧数据（例如主控线程被调度延迟数十 ms） | 定长 9 字节帧 + 双帧头同步天然消解：每轮循环只消费"1+1+7"恰好所需字节，多余字节留在缓冲区由下一轮消费；一旦失步，逐字节扫描可跳过任意数量的杂散/积压字节直到重锁帧头 |
| **半包 (Fragmentation)** | `ser.read(7)` 在 timeout 窗口内未收满 7 字节（USB-串口驱动分片、缓冲不足） | `len(frame) != 9` 判定 → 整帧作废 → 回 S0 重同步。作废是**安全**的：半包数据不可能通过校验和（错位字节必破坏累加和），不存在"半包被误采纳"路径 |
| **陈旧积压数据** | 线程启动前传感器已持续输出，缓冲区存满历史帧 | `_loop` 打开串口后立即 `ser.reset_input_buffer()` 清空输入缓冲，保证首帧即"新数据" |

**`timeout=0.1` 参数的三重意义**：

```python
ser = serial.Serial(self.port, self.baudrate, timeout=0.1)   # timeout = 0.1 s
```

1. **防永久阻塞**：单次 `read(n)` 最多阻塞 100 ms 后返回已收到的字节（可能少于 n）。若无 timeout，`read(1)` 在链路静默时将永久挂起，`stop()` 置位 `running=False` 后线程仍无法退出检查点。
2. **半包判定的时间上限**：`read(7)` 的等待窗口即半包判定窗。正常帧间隔 10 ms（100 Hz），帧内 9 字节连续到达仅需 ~0.78 ms，**100 ms ≫ 帧周期 12.5 倍**，正常运行绝不误触发；仅链路异常（拔线、传感器断电）时触发作废-重同步循环。
3. **异常退出的响应时延上界**：传感器断开后，线程每 100 ms 完成一次 `read` 返回 → 循环回到 `while self.running` 检查 → `stop()` 后最迟 ~0.2 s 内线程退出。

### 4.5 内部温度字段解析公式与物理量提取

**温度字段的协议定义**（模数转换链：raw 16-bit → 物理摄氏度）：

$$
T_{int} = \frac{\text{Temp\_L} + (\text{Temp\_H} \ll 8)}{8} - 256 \quad [^\circ\text{C}]
$$

即 raw 值量化步长 0.125 ℃、零点偏移 −256 ℃ 的 16-bit 有偏编码，覆盖传感器内部芯片温度监控区间。

**源码未解析字段的说明**：

| 字段 | 源码是否解算 | 未解析理由（工程取舍） |
| :--- | :---: | :--- |
| `Temp_L` / `Temp_H` (Byte 6/7) | 否 | 温度为传感器**自身芯片**的监控量，与目标距离/反射率业务无关；跟踪控制律仅消费 `distance` 与 `strength` |
| `Temp` 参与校验和吗 | **是（间接）** | 虽不解算，但 `Temp_L/Temp_H` 计入 `sum(frame[0:8])` —— **校验和覆盖全帧 8 字节**，保证完整性校验无盲区；这就是"不消费但必须参与校验"的协议设计要点 |
| `Strength` 的二次用途 | 半解析 | 解算并写入共享变量（`self.strength`），供上层做信号质量诊断；仅作为过滤门限（>100，≠65535）参与决策 |

### 4.6 串口链路时序预算 (100Hz 数据率)

UART 8N1 每字节 = 1 起始位 + 8 数据位 + 1 停止位 = **10 bit**：

| 指标 | 计算 | 数值 |
| :--- | :--- | :---: |
| 单帧位数 | 9 字节 × 10 bit | 90 bit |
| 单帧传输耗时 | 90 bit / 115200 bps | **≈ 781 μs** |
| 帧周期 | 1 / 100 Hz | 10 ms |
| **链路占用率** | 781 μs / 10 ms | **≈ 7.8%** |
| 帧间空闲 | 10 ms − 781 μs | ≈ 9.22 ms |

链路占用 7.8%，空闲裕量充足；主控侧逐字节读取（3 次 `read` 调用/帧）的 CPU 开销在 100 Hz 帧率下可忽略。

---

## 5. 嵌入式 Linux SocketCAN 实现层

### 5.1 can.Message 报文对象结构

源码通过 **python-can** 库的 SocketCAN 接口发送报文，核心调用链（`gimbal_can.py`）：

```python
self.bus = can.interface.Bus(channel=channel, interface="socketcan")   # 绑定 can0 (PF_CAN)

def send(self, can_id, data):
    msg = can.Message(arbitration_id=can_id, data=data, is_extended_id=False)
    self.bus.send(msg, timeout=0.05)
```

`can.Message` 关键字段与本系统的取值约定：

| 字段 | 类型 | 本系统取值 | 语义 |
| :--- | :--- | :--- | :--- |
| `arbitration_id` | int | `0x201` / `0x202` | 11 位标准帧标识符（Mode 2 ≪ 8 \| Node ID） |
| `is_extended_id` | bool | **`False`（强制）** | **False → 11-bit 标准帧**；若误置 True 将发出 29-bit 扩展帧，GL40 无法识别（见第 7 章协议辨析） |
| `is_remote_frame` | bool | `False`（默认） | 数据帧而非遥控帧 |
| `data` | bytes / iterable | ≤ 8 字节 | 速度帧：`pack_speed()` 输出；命令帧：`FF×7+FC/FD` 等 |
| `dlc` | int | 由 `len(data)` 自动推导 | 本系统恒为 8 |
| `timestamp` / `is_rx` | float / bool | 接收方向由内核打戳 | 发送报文无需关注 |

### 5.2 bus.send 发送超时语义与 ENOBUFS 防护

`bus.send(msg, timeout=0.05)` 的底层行为链路：

```
python-can send()
  → write() 到 PF_CAN socket
    → 内核 CAN 协议栈 (TX 队列, netdev txqueuelen 默认 10)
      → CAN 网卡驱动 (如 mcp251x SPI 驱动)
        → 控制器硬件邮箱 / FIFO
          → ISO 11898-2 收发器 → 总线
```

| 场景 | 行为 |
| :--- | :--- |
| TX 队列有空位 | 立即入队返回（**异步发送语义**：入队成功 ≠ 总线上已发出；错误帧重传由硬件自动完成） |
| TX 队列已满 | `write` 阻塞，等待至多 **0.05 s**（内部 poll）；仍无空位则底层返回 `EAGAIN`（队列满时亦表现为 `ENOBUFS`），python-can 抛出 `can.CanError` 异常 |
| 接口未 up / 不存在 | 抛出 `OSError`（`Network is down` 等），通常意味着 `ip link set can0 up type can bitrate 1000000` 未执行 |

**本项目场景分析**：两帧间隔 5 ms ≫ 单帧占用 ~0.13 ms（130 bit @ 1Mbps），且 `txqueuelen=10` 的默认队列深度相对每周期 2 帧的流量宽裕 5 倍以上，**TX 队列溢出在本负载模型下不可能发生**；`timeout=0.05` 属于防御性编程——为总线级异常（如 Bus Off 期间发送、驱动卡死）提供 50 ms 内可观测的失败路径，避免上层控制线程无界阻塞破坏 20 ms 实时周期。

### 5.3 candump / cansend 报文格式与实战命令集

`can-utils` 的帧文本格式：

```
candump 输出:   <接口>  <ID(3位16进制)>   [<DLC>]  <数据字节流>
示例:           can0  201   [8]  CD CC CC 3D 00 00 00 00

cansend 输入:   <ID>#<数据(连续16进制, 长度=DLC×2)>
示例:           201#CDCCCC3D00000000
```

树莓派终端实战命令集：

```bash
# 0. 首次配置 CAN 接口 (1Mbps 与协议锚点一致)
sudo ip link set can0 down
sudo ip link set can0 up type can bitrate 1000000

# 1. 监听 can0 网卡所有报文
candump can0

# 2. 过滤监听电机反馈报文 (回传 Master ID 0x000, 掩码 0x7FF 精确匹配)
candump can0,000:7FF

# 3. 手动下发使能指令 (Yaw 电机 0x201 使能)
cansend can0 201#FFFFFFFFFFFFFFFC

# 4. 手动下发失能指令 (Yaw 电机 0x201 失能)
cansend can0 201#FFFFFFFFFFFFFFFD

# 5. 手动下发速度指令 (Yaw 电机 0x201, 速度 0.1 rad/s)
#    0.1 的 float32 为 0x3DCCCCCD, 小端字节流 CD CC CC 3D (推导见 3.3.3)
cansend can0 201#CDCCCC3D00000000

# 6. 手动下发速度指令 (速度 0.0 rad/s 停转)
cansend can0 201#0000000000000000

# 7. 设机械零点 / 清错误 (协议支持, 源码未封装, 调试期可用)
cansend can0 201#FFFFFFFFFFFFFFFE
cansend can0 201#FFFFFFFFFFFFFFFB

# 8. 对 Pitch 轴 (0x202) 执行同样操作
cansend can0 202#FFFFFFFFFFFFFFFC
cansend can0 202#CDCCCC3D00000000
```

**抓包判读要点**：`candump` 观察到 `can0  000   [8] ...` 即为 GL40 回传的遥测帧，其 Byte 0 高 4 位即为 ERR 故障码（3.4 节码表）；若完全无 `000` 帧，需检查驱动器反馈上报配置或总线物理层。

### 5.4 协议要素与源码逐行追溯表

协议规范与源码实现的对应关系（防止规范-实现漂移的审计锚点）：

| 协议要素 | 规范锚点 | 源码位置 (`gimbal_can.py` / `tfmini_uart.py`) |
| :--- | :--- | :--- |
| 1 Mbps 标准帧 | ISO 11898-1/2 + GL40 V1.0.0 | `can.Message(..., is_extended_id=False)` |
| SocketCAN 绑定 | Linux `Documentation/networking/can.txt` | `can.interface.Bus(channel, interface="socketcan")` |
| ID 编址公式 | `(Mode≪8) \| Node ID` | `self.yaw_id = 0x201`、`self.pitch_id = 0x202` |
| 使能 / 失能命令 | `FF×7+FC` / `FF×7+FD`，DLC=8 | `self.enable_cmd` / `self.disable_cmd` |
| 速度帧封装 | float32 小端 + 4×`0x00` 填充 | `pack_speed(): struct.pack("<f", float(vel)) + bytes([0x00]*4)` |
| 轴间 5ms 延时 | 3.6 节时序冗余设计 | `send_speed(): send_yaw → time.sleep(0.005) → send_pitch` |
| 发送超时保护 | 5.2 节超时语义 | `self.bus.send(msg, timeout=0.05)` |
| 串口参数 | 115200 8N1 @ `/dev/serial0` | `serial.Serial(self.port, self.baudrate, timeout=0.1)` |
| 双帧头同步 | 4.3 节 FSM | `_read_frame(): b==0x59, b2==0x59` |
| 校验和 | `ΣB[0..7] mod 256` | `checksum = sum(frame[0:8]) & 0xFF` |
| 三重门限过滤 | 4.1 节表 + 4.2 节 | `valid = strength > 100 and strength != 65535 and distance != 0` |
| 线程安全数据更新 | 4.3 节 S5 状态 | `with self.lock: self.distance = ...` |

---

## 6. 控制周期报文时序流水线

跟踪控制循环以 50 Hz（T = 20 ms）运行，每周期调用一次 `send_speed(yaw_vel, pitch_vel)`，内部时序如下（按保守帧长 130 bit ≈ 0.13 ms 计）：

```mermaid
sequenceDiagram
    autonumber
    participant CTL as 控制线程 (50Hz)
    participant BUS as CAN 总线 1Mbps
    participant Y as GL40 Yaw (0x201 / Node 1)
    participant P as GL40 Pitch (0x202 / Node 2)

    Note over CTL: t = 0 ms — 周期起点 (T = 20ms)
    CTL->>BUS: send_speed(yaw_vel, pitch_vel)
    CTL->>BUS: 帧① 0x201 [8] vel_f32_LE + 00×4 (≈130bit ≈ 0.13ms)
    BUS->>Y:仲裁→接收→CRC校验→ACK→执行
    Y-->>BUS: 反馈帧 → Master 0x000 (ERR/位置/速度/扭矩/温度)

    Note over CTL: time.sleep(0.005) — 5ms 轴间防冲突延时
    CTL->>BUS: 帧② 0x202 [8] vel_f32_LE + 00×4 (t ≈ 5.0ms)
    BUS->>P:仲裁→接收→CRC校验→ACK→执行
    P-->>BUS: 反馈帧 → Master 0x000

    Note over CTL,BUS: t ≈ 5.3ms 后总线完全空闲 (空闲率 >97%)
    Note over CTL: t = 20ms — 下一周期 (帧①帧②永不竞争: 串行下发)
```

**时序量化表**（单周期 20 ms 预算）：

| 时间片 | 时长 | 总线状态 | 说明 |
| :--- | :---: | :--- | :--- |
| t = 0 ~ 0.13 ms | 0.13 ms | 帧① `0x201` 占线 | 130 bit 保守帧长（含填充与 IFS） |
| t = 0.13 ~ 0.26 ms | ~0.13 ms | 反馈帧①（若使能应答）占线 | 0x000 遥测帧 |
| t = 0.26 ~ 5.0 ms | 4.74 ms | **总线空闲** | `time.sleep(0.005)` 软件延时 |
| t = 5.0 ~ 5.13 ms | 0.13 ms | 帧② `0x202` 占线 | 同帧① |
| t = 5.13 ~ 5.26 ms | ~0.13 ms | 反馈帧②（若使能应答）占线 | |
| t = 5.26 ~ 20 ms | 14.74 ms | **总线空闲** | 占空比 < 2%，裕量见 3.6 节 |

**5 ms 轴间延时的定位**：在 1.3% 负载率下，总线仲裁层面两帧根本不会冲突，该延时的价值在于：(1) 为 MCP2515 等控制器硬件邮箱与 SPI 配置路径留出清空窗口，规避驱动层排队边界；(2) 给从机驱动板中断处理与上帧执行留出处理间隔，降低固件层并发解析风险；(3) 保持 `send_speed` 调用语义的确定性，便于示波器/`candump` 抓包比对。属于"以 5ms 微小成本换取多层级稳健裕量"的工程决策。

---

## 7. 电机通信协议辨析 (与 29 位扩展帧协议的差异)

CubeMars GL40 驱动器采用专用的 11 位标准帧协议。与常见 29 位扩展帧微电机协议相比，其通信机制差异如下：

| 对比维度 | CubeMars GL40 (本系统采用) | 常见 29 位扩展帧运控协议 |
| :--- | :--- | :--- |
| **帧 ID 格式** | **11 位标准帧** (`is_extended_id=False`) | 29 位扩展帧 (`is_extended_id=True`) |
| **节点寻址机制** | 高 3 位模式编码 + 低 8 位电机 ID 单帧组合 | 目标地址、源地址与通信类型跨多个位段组合 |
| **速度控制数据载荷** | **前 4 字节直接存放 float32 小端单精度浮点数** | 速度与扭矩多采用 12 位或 16 位整型位压缩映射 |
| **驱动接口实现** | 纯 Python 标准库 `struct.pack("<f", vel)` 即可打包 | 需编写专用的位解包函数与缩放比例映射 |

源码实现事实：
- `gimbal_can.py:18` 明确声明了 `is_extended_id=False`；
- 控制 ID 取值 `0x201` 与 `0x202`，完全符合 GL40 模式 2 速度控制的基底规范。

---

## 8. 双协议位域综合总图 (SVG 矢量图)

通信协议二进制位域布局与数据帧格式

---

## 9. 参考资料

| # | 文献 / 标准 | 版本 / 年份 | 在本规范中的作用 |
| :---: | :--- | :--- | :--- |
| 1 | **Bosch CAN Specification, Robert Bosch GmbH** | Version 2.0 (Part A/B)，1991 | 第 2 章 CAN 2.0B 帧结构、逐位仲裁、位填充、错误界定机制的原始依据 |
| 2 | **ISO 11898-1:2015** — Road vehicles — Controller area network (CAN) — Part 1: Data link layer and physical signalling | ISO, 2015 | 数据链路层（LLC/MAC、TEC/REC 错误计数规则）的国际化标准表述 |
| 3 | **ISO 11898-2:2016** — Part 2: High-speed medium access unit | ISO, 2016 | 1 Mbps 物理层、显性/隐性电平、120 Ω 终端匹配 |
| 4 | **CiA 301** — CANopen application layer and communication profile | CiA v4.2+ | 应用层协议设计的行业参考框架；采样点 87.5% 配置惯例 |
| 5 | **CubeMars《GL 系列模组驱动使用说明》** | V1.0.0，2024-07-18 | 第 3 章全部应用层报文定义（ID 编址、命令集、速度帧、遥测帧、电气规格、PWM 模式）——项目附件 `【协议手册】GL40模组驱动使用说明.pdf` |
| 6 | **北醒 (Benewake)《TFmini Plus 激光测距模块产品用户手册》** | 官方现行版 | 第 4 章帧结构、校验和、温度换算、量程/盲区/帧率指标 |
| 7 | **IEC 61162 系列** — Maritime navigation and radiocommunication equipment and systems — Digital interfaces | IEC | 串行"定长帧 + 校验和"协议设计的行业标准范式参照（第 1.2 节设计注记） |
| 8 | **Linux SocketCAN 官方文档** — `Documentation/networking/can.txt` | kernel.org | 第 5 章 PF_CAN 套接字、`candump`/`cansend` 用法 |
| 9 | **python-can 官方文档** — SocketCAN Interface | python-can 项目 | `can.interface.Bus` / `can.Message` / `bus.send(timeout)` 语义 |
| 10 | **IEEE 754-2019** — Standard for Floating-Point Arithmetic | IEEE | 3.3 节 float32 编码推导 |

---

> **文档效力声明**：本规范第 2、4 章的 CAN 链路层与串口组帧内容为标准符合性描述；第 3、5 章的应用层报文与实现细节均以项目源码（`gimbal_can.py`、`tfmini_uart.py`）与 CubeMars V1.0.0 手册为唯一事实来源，未经源码验证的推断均已显式标注"以手册为准"。后续任何报文定义变更须同步修订本表（5.4 节追溯表）并回归 `candump` 抓包验证。

---

## 附录 常用术语与缩略语

| 缩略语 | 英文全称 | 中文释义 |
| :--- | :--- | :--- |
| **CAN** | Controller Area Network | 控制器局域网（ISO 11898 系列现场总线） |
| **SOF** | Start Of Frame | 帧起始位（显性 0） |
| **RTR** | Remote Transmission Request | 远程发送请求位（数据帧显性，遥控帧隐性） |
| **IDE** | Identifier Extension | 标识符扩展位（标准帧显性，扩展帧隐性） |
| **DLC** | Data Length Code | 数据长度码（4 bit，取值 0~8） |
| **CRC** | Cyclic Redundancy Check | 循环冗余校验（CAN 使用 15 位 CRC） |
| **ACK** | Acknowledgement | 应答（ACK 槽 + ACK 界定符） |
| **EOF** | End Of Frame | 帧结束（7 个连续隐性位） |
| **IFS** | InterFrame Space | 帧间空间（3 个连续隐性位） |
| **TEC / REC** | Transmit / Receive Error Counter | 发送 / 接收错误计数器 |
| **Tq** | Time Quantum | 位时序的最小时间单元 |
| **NBT** | Nominal Bit Time | 标称位时间（1 Mbps 下为 1 μs） |
| **SP** | Sample Point | 采样点（位时间内读取总线电平的时刻） |
| **FOC** | Field-Oriented Control | 磁场定向控制（矢量控制） |
| **ADRC** | Active Disturbance Rejection Control | 自抗扰控制 |
| **ToF** | Time of Flight | 飞行时间测距原理 |
| **LE** | Little-Endian | 小端字节序（低字节在前） |
| **UVLO / OCP** | Under-Voltage Lockout / Over-Current Protection | 欠压锁定 / 过流保护 |

---

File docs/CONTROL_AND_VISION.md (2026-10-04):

# 跟踪云台视觉感知与速度模式双轴闭环控制规范 (TRK-GMB-CTRL-SPEC-001)












---

## 1. 需求与验收准则分析 (Requirements & Criteria)

### 1.1 设计哲学与失效安全原则

本系统的设计遵循航空机载软件的三条铁律，并据此裁剪控制律复杂度：

1. **可证明性优先于最优性**：选用"带死区的比例速度控制"而非 PID/MPC，目的是让闭环稳定性可由一阶特征根 $\lambda = -f_x K_p$ 直接解析证明（见第 3.3、4.5 节），杜绝有人飞行器"驾驶员诱发振荡（PIO）"式的极限环风险。
2. **失效安全（Fail-safe）优先**：目标丢失（`detect_faces` 返回空）立即执行 `gimbal.stop()` 零速指令；进程异常退出时 `finally` 块仍执行 `stop → disable`，保证电机进入抱闸态而非失控。
3. **名义线性的显式边界**：死区 $D=15\,\text{px}$ 把稳态精度让渡给抗抖动；限幅参数 $v_{\min}/v_{\max}$ 被证明为永不触发的守卫项（见 3.2 节），其作用是防御未来参数改动，而非在线调参。

### 1.2 控制律需求规格与追溯矩阵 (CRT-REQ 系列)

> 验证方法分类遵循 SAE ARP4754A 范式：**Inspection**（源码审查）、**Demonstration**（台架/实飞演示）、**Analysis**（解析/仿真分析）。

| 需求 ID | 类别 | 需求描述 | 量化判据 | 理论/源码追溯 | 验证方法 | 验证章节 |
| :---: | :---: | :--- | :--- | :--- | :--- | :--- |
| CRT-REQ-001 | 跟踪速率 | 死区外任意像素偏移均须输出非零云台速度；最大指令速度须覆盖人体步行角速率 | $|e|>15\,\text{px} \Rightarrow v\neq 0$；$|v|_{\max}=0.96\,\text{rad/s}$（yaw） | `calc_speed`；3.2 节起跳分析 | Inspection | §3.2 |
| CRT-REQ-002 | 稳态精度 | 人脸中心须收敛至中心死区盒内并保持 | $\|(e_x,e_y)\|_\infty \le 15\,\text{px}$ | `DEADZONE_X/Y=15`；§4.5 UUB | Demonstration | §9.1 |
| CRT-REQ-003 | 收敛时间 | 220 px 阶跃偏差须在规定时间内进入死区 | $t \le 3.5\,\text{s}$（$\tau=1.33\,\text{s}$，理论值） | §3.3 $\lambda=-0.75\,\text{s}^{-1}$ | Analysis | §9.1 |
| CRT-REQ-004 | 动态品质 | 闭环须无超调、单调收敛 | $\max_t \dot e$ 不改变符号（一阶系统） | §3.3、§4.5 | Analysis | §9.1 |
| CRT-REQ-005 | 抖动抑制 | 目标在死区内静止时输出零速，不允许极限环/电机啸叫 | $|e|\le15\,\text{px} \Rightarrow v=0.0$；无持续振荡 | §3.7 描述函数 | Demonstration | §9.1 |
| CRT-REQ-006 | 周期纪律 | 控制指令下发标称周期 | $T_c = 20\,\text{ms}$（50 Hz） | `CONTROL_PERIOD=0.02` | Analysis | §6.1 |
| CRT-REQ-007 | 失效安全 | 目标丢失时零速；进程退出时抱闸 | `face is None → gimbal.stop()`；`finally: stop→disable` | main.py:153-154, 165-168 | Inspection | §8 |
| CRT-REQ-008 | 感知可用性 | 检测器输出格式须满足下游接口契约 | `detect_faces` 返回 `(list, dict)`，含 `cx/cy/area` 键 | camera_yunet.py:54-79 | Inspection | §8.1 |

### 1.3 失效模式危害性等级定义

| 等级 | 定义（按 MIL-STD-882F 思想归纳） | 本系统失效模式例 | 设计对策 |
| :---: | :--- | :--- | :--- |
| 灾难性 I | 人员死亡或系统全损 | 电机指令饱和 + 云台撞击限位（当前参数下不可达） | $v_{\max}$ 守卫 + 机械限位 |
| 严重 II | 人员受伤 / 任务严重失败 | 目标丢失后仍持续发令（**当前设计不存在**：`else: gimbal.stop()`） | 零速默认态 |
| 边缘 III | 任务降级但可降级运行 | BUG-01/02 导致跟踪功能完全失效（失效安全停机） | 见第 8 章整改 |
| 轻微 IV | 轻微或可忽略影响 | BUG-03 色序错误导致置信度漂移、OSD 配色翻转 | 删除 `cvtColor` 注释 |

### 1.4 需求追溯链

```
系统任务（人脸跟随）
 └─CRT-REQ-001/002/003 ──► 控制律 v(e)=k·e（死区版） ──► calc_speed()
 │                              │
 │                              ├─► λ=-f·Kp=-0.75 s⁻¹（§3.3/§3.4 连续+离散双重证明）
 │                              └─► PM≈88.7°（§3.6 频域裕量）
 ├─CRT-REQ-005 ──► 死区 15px（§3.7 描述函数：无极限环）
 ├─CRT-REQ-006 ──► 20ms 预算（§6.1/§6.3）
 └─CRT-REQ-007/008 ──► 接口契约（§8 缺陷机理 + §9 V&V 矩阵）
```

---

## 2. 视觉感知管线与目标决策 (Vision Pipeline)

### 2.1 相机与 YuNet 实例化参数矩阵

以下参数为源码事实基线（`camera_yunet.py`），任何设计与验收结论均以此为准：

| 参数 | 数值 | 源码位置 | 工程含义 |
| :--- | :--- | :--- | :--- |
| 传感器 | IMX219（对角 FOV ≈ 130°） | — | 广角近距跟踪 |
| 捕获分辨率 | 1640 × 1232，RGB888 | `capture_size` / `create_video_configuration` | 2×2 binning 全幅读出 |
| 处理/推流分辨率 | 640 × 480 | `stream_size`；`cv2.resize` | 4:3 保持，未裁剪 |
| 帧率约束 | `FrameDurationLimits=(20000, 20000)` | `set_controls` | 硬锁定 50 fps |
| AeEnable / AwbEnable | True / True | `set_controls` | 硬件 3A 闭环 |
| 启动稳定延时 | `time.sleep(1)` | `__init__` | 等待 3A 收敛后再建检测器 |
| 模型路径 | `/home/jr/models/face_detection_yunet_2023mar.onnx` | `FaceDetectorYN.create` 第 1 参 | 2023mar 权重 |
| 输入尺寸 | (640, 480) | 第 3 参 + `setInputSize`（每帧重置） | 网络输入张量 [1,3,480,640] |
| 置信度门限 | `score_threshold=0.6` | 命名参 | 抑制虚警 |
| NMS 门限 | `nms_threshold=0.3` | 命名参 | 重叠框合并 |
| 候选池 | `top_k=5000` | 命名参 | 多脸/密集场景保留上限 |
| 输出契约 | `([{x,y,w,h,cx,cy,area}], selected=max(area))` | `detect_faces` | 元组返回 |

### 2.2 片上 ISP 图像预处理流水线 (Mermaid)

从 CMOS 曝光到检出人脸边界框的端到端张量管线。耗时标注引自第 6.1 节实测预算。

```mermaid
flowchart LR
    subgraph CMOS_HW["IMX219 传感器硬件"]
        RAW_CFA["原生 Bayer CFA 阵列<br/>1640×1232 原始数据"]
    end

    subgraph RPI_ISP["树莓派片上硬件 ISP 引擎（3A 闭环）"]
        BLC["黑电平校准 BLC"]
        LSC["镜头阴影衰减补偿 LSC"]
        DEMOSAIC["去马赛克插值 Demosaic"]
        AWB_AE["硬件 3A 闭环<br/>AeEnable=True, AwbEnable=True"]
        FMT_OUT["RGB888 格式输出<br/>50 fps 硬锁定"]
    end

    subgraph SW_PIPELINE["Python 端处理流水线 [耗时标注]"]
        RESIZE["cv2.resize 双线性插值<br/>1640×1232 ➔ 640×480<br/>[4.2 ms, 21%]"]
        COLOR_FIX["cvtColor RGB ➔ BGR<br/>⚠ 当前被注释 (BUG-03)"]
        YUNET_INF["FaceDetectorYN 推理<br/>输入 [1, 3, 480, 640] 张量<br/>[11.8 ms, 59%]"]
        NMS_FILTER["置信度 > 0.6<br/>NMS > 0.3 抑制"]
        TARGET_PICK["最大面积准则<br/>max(w × h) ➔ selected"]
    end

    RAW_CFA --> BLC --> LSC --> DEMOSAIC --> AWB_AE --> FMT_OUT
    FMT_OUT --> RESIZE --> COLOR_FIX --> YUNET_INF --> NMS_FILTER --> TARGET_PICK
```

> [!NOTE]
> **ISP 初始化与 3A 收敛时序**
> 底层图像采集在调用 `picamera2.start()` 后，必须先执行 `set_controls({AeEnable, AwbEnable, FrameDurationLimits})` 配置自动曝光与帧率，并主动延时 `time.sleep(1)`。
> 该延时确保片上 ISP 的自动白平衡 (AWB) 与自动曝光 (AE) 达到稳态收敛，避免首帧图像过曝或偏色导致 YuNet 检测置信度暴跌。

### 2.3 针孔透视成像几何与激光雷达同轴投影 (SVG 矢量图)

针孔成像几何建立三维目标点 $P(X_c,Y_c,Z_c)$ 到像平面像素 $(u,v)$ 的投影关系。主光轴 $+Z_c$ 水平对齐像主点 $c_0(320,240)$；TFmini 激光雷达安装于相机正上方（垂直基线偏置 $b_y=28\,\text{mm}$），发射平行主光轴的 850 nm 测距脉冲——该偏置是"视觉中心对准目标"与"测距点对准目标"之间的微小系统误差源（对角 FOV ≈ 130°，旁轴近似下影响可忽略）。

针孔成像几何模型与空间同轴测距投影

### 2.4 像平面视场几何定义与死区盒空间分布

```text
(0,0) 原点                                                   (640,0)
  +-------------------------------------------------------------+
  |                                                             |
  |             ^ -Y (Pitch 电机上仰，PITCH_DIRECTION = +1)     |
  |             |                                               |
  |             |                                               |
  |             |       死区边界 Y = 240 ± 15                   |
  |             |       +-------------+                         |
  |    <--------+-------|  死区核心盒 |-------+-------->        |
  | -X (Yaw 左偏)       |  (速度 = 0) |       |  +X (Yaw 右偏)  |
  |                     +-------------+                         |
  |                     死区边界 X = 320 ± 15                   |
  |             |                                               |
  |             |                                               |
  |             v +Y (Pitch 电机下俯)                           |
  |                                                             |
  +-------------------------------------------------------------+
(0,480)                                                       (640,480)
基准中心: (cx0, cy0) = (320, 240)
有效跟踪视场: 640×480 px, 对角视场角 FOV ≈ 130°
```

| 轴向 | 像素极性 | 物理运动方向 | `direction` 常量 | 依据 |
| :--- | :--- | :--- | :---: | :--- |
| Yaw | $+e_x$（人脸偏右） | 云台**向右**回转使像回中 | `YAW_DIRECTION=-1` | main.py:17 |
| Pitch | $+e_y$（人脸偏下） | 云台**下俯**使像回中 | `PITCH_DIRECTION=+1` | main.py:18 |

> 方向符号的物理依据（§4.4）：像点速度 $\dot e_x \approx -f_x\omega_{\text{yaw}}$，负号表示云台右转使右偏目标左移回中；`-1` 极性因子与之一致。两轴符号不一致性已通过 `direction` 参数显式解耦，属**已批准的设计约定**而非缺陷。

### 2.5 YuNet 网络架构深析：单级卷积检测器

1. **网络定位**：YuNet 属 RetinaFace 谱系的极简化分支——单级（single-stage）、anchor-free 密集预测、面向边缘 CPU 设计。其骨干为轻量可分离卷积堆叠 + 类 FPN 多尺度融合，无大核、无重 neck，故能在 100 MHz 级主频上达实时。
2. **多任务输出头**（对应用户关心的输出张量结构）：
   - **分类头 cls（2 通道）**：前景/背景二分类，经 `score_threshold=0.6` 门限；
   - **边框回归头 box（4 通道）**：框心与宽高的归一化偏移量；
   - **关键点头 landmark（10 通道）**：**5 点 landmark（双眼、鼻尖、双嘴角）× 2 坐标**，共 10 维。
   - 输出经 OpenCV DNN 内部解码 + `nms_threshold=0.3` NMS + `top_k=5000` 截断，最终以 `N×15` 数组返回（前 4 列为 x,y,w,h，第 15 列常为综合得分，本系统仅取前 4 列与面积）。
3. **2023mar 权重改进**：相较初代，2023mar 版在 chair-level CPU 延迟基本不变的前提下，通过训练数据增广与标签分配优化小幅提升了小人脸与小角度侧脸召回；这也是源码固定使用 2023mar 的原因。
4. **算力分析（Cortex-A53 @ 1.0 GHz，实测 11.8 ms/帧）**：
   - YuNet 2023mar 的计算量处于 $10^{-1}$ GFLOPs 量级（依据 OpenCV Zoo 公布的基准量级）；
   - 折合有效算力：$\approx 0.1\times10^9 / 11.8\times10^{-3} \approx 8.5\,\text{GFLOP/s}$，即约每核 2 GFLOP/s——对无 NEON 加速的 A53 标量峰值（~2–4 GFLOP/s 量级）而言，说明 OpenCV DNN 的 CPU 后端已用 NEON + OpenMP 多核摊还；**进一步的加速空间在于换 NPU/后端，而非改模型**。
   - 输入 640×480×3 float32 张量 ≈ 3.7 MB/帧的内存驻留，与 `top_k=5000` 的候选池一起，构成 Zero 2 W（512 MB）上的主要内存压力。

### 2.6 最大面积准则的物理意义与工程权衡

$$
\text{Target} = \arg\max_{f \in \text{Faces}} (f.w \times f.h)
$$

- **物理意义**：在针孔模型下，同一物理尺寸目标的像面积 $S \propto 1/Z_c^2$，"面积最大"即"距离最近"，构成**最近脸代理指标**；同时大面积目标通常对应更高置信度与更多可用纹理，是自然形成的显著性（salience）代理。
- **工程局限**（已作为认知风险登记）：
  1. 面积准则不含航迹关联，两目标交错时可发生目标 ID 跳变，引发控制输入阶跃式扰动（由 15 px 死区与 1.33 s 时间常数弱化，见 §3.7）；
  2. 大面积侧脸/遮挡脸可能排挤正脸小目标，属任务语义（最近 vs 最可跟踪）的取舍，本规范按源码现状取"最近"语义；
  3. 面积准则非李雅普诺夫函数构造出的，不能单独作为稳定性论据（稳定性由 §4.5 的误差动力学给出）。

### 2.7 目标状态机与视觉伺服任务语义 (Mermaid)

`draw_overlay` 的准星颜色即状态机的外部观测：红 = 寻的/未连线中心，绿 = 锁定。

```mermaid
stateDiagram-v2
    [*] --> LOST
    LOST --> SEARCH: detect_faces 返回空列表
    SEARCH --> LOST: 检测到候选脸
    SEARCH --> TRACK: selected = max(area) 生效，e ≠ 0
    TRACK --> LOCK: 人脸框包含像主点 (320,240) ➔ 绿准星
    LOCK --> TRACK: 人脸框移出主点 ➔ 红准星
    TRACK --> LOST: 目标移出视场 ➔ 空列表
    LOST --> [*]: gimbal.stop() 并保持零速

    note right of LOST
        零速默认态（失效安全）
        gimbal.stop() 全零指令
    end note
    note right of TRACK
        比例速度指令 v(e)
        OSD: faces / err_x / err_y
    end note
    note right of LOCK
        |e| 逐轴 ≤ 15px
        OSD 准星变绿 (0,255,0)
    end note
```

### 2.8 视场平面合成角速度热力分布 (SVG 矢量图)

在 640×480 视场内，双轴合成角速度模长 $\|\omega\|=\sqrt{\omega_{\text{yaw}}^2+\omega_{\text{pitch}}^2}$ 的空间分布：

视场平面目标分布与驱动速度模长热力拓扑

> 读图要点：死区盒 $[-15,15]^2$ 为速度零值"平顶"；盒外速度幅值随 $|e|$ 线性扩张，因 `direction` 极性在四个象限形成反对称条纹；yaw 方向最大 0.96 rad/s，pitch 方向最大 0.72 rad/s（$|e_y|_{\max}=240\,\text{px}$），故云图上下边缘等值线先于左右边缘收敛。

---

## 3. 控制律数学建模与动力学分析 (Control Modeling)

### 3.1 比例速度控制闭环结构图与参数矩阵 (SVG 矢量图)

设画面基准中心 $(cx_0,cy_0)=(320,240)$（`CENTER_X/Y`），目标中心 $(cx,cy)=(x+w/2,\,y+h/2)$，则像素偏差：

$$
e_x = cx - 320, \qquad e_y = cy - 240
$$

控制函数 $v(e)$（`calc_speed`，main.py:39-49）为带死区的比例截断映射：

$$
v(e) = \begin{cases} 
0.0, & |e| \le D \\ 
\text{clamp}\big(|e| \cdot K_p,\; v_{\min},\; v_{\max}\big) \cdot \text{sgn}(e) \cdot \text{Direction}, & |e| > D 
\end{cases}
$$

式中参数说明：
- $e$：目标人脸中心相对画面基准中心的像素偏差（单位：$\text{px}$）；
- $D$：抗微颤死区半宽阈值，固定为 $15\,\text{px}$；
- $K_p$：比例速度增益系数，设定为 $0.003\,\text{rad/s/px}$；
- $v_{\min}, v_{\max}$：算法理论速度限幅区间，设定为 $[0.02, 100.0]\,\text{rad/s}$；
- $\text{Direction}$：轴向运动极性修正因子（偏航轴为 $-1$，俯仰轴为 $+1$）。

| 轴向控制变量 | 比例增益 $K_p$ | 死区阈值 $D$ | 理论限幅区间 $[v_{\min},v_{\max}]$ | 方向极性 | 实际工作输出极值 | 最大像素偏差 |
| :--- | :---: | :---: | :---: | :---: | :---: | :---: |
| **Yaw 航向轴** | `0.003` rad/s/px | `15` px | `[0.02, 100.0]` rad/s | `-1` | $\pm[0.048,\,0.96]\ \text{rad/s}$ | $|e_x|_{\max}=320$ px |
| **Pitch 俯仰轴** | `0.003` rad/s/px | `15` px | `[0.02, 100.0]` rad/s | `+1` | $\pm[0.048,\,0.72]\ \text{rad/s}$ | $|e_y|_{\max}=240$ px |
| 控制周期 | $T=0.02\,\text{s}$（50 Hz） | — | — | — | `CONTROL_PERIOD` | — |

### 3.2 控制律三大工程特性解构 (跳变与限幅失效)

1. **死区边界非连续起跳（Boundary Step，满足 CRT-REQ-001）**：
   误差越过 $|e|=15\,\text{px}$ 的瞬间，速度不连续跃升至

$$
v_{\text{start}} = 16 \times 0.003 = 0.048\ \text{rad/s} \approx 2.75^\circ/\text{s}
$$

   该跃阶用于克服无刷电机轴承静摩擦与导电滑环 Stiction，属**有意引入的"起跳力矩"**，代价是 3.2~3.4 节展示的弱非线性（由描述函数法证明无害）。
2. **理论最小限幅 $v_{\min}=0.02$ 为死代码（Dead Code）**：
   因 $v_{\text{start}}=0.048 > 0.02$，死区外一切输入下 `clamp` 的下界永不生效；该参数仅在未来下调 $K_p$ 时提供地板保护。
3. **理论最大限幅 $v_{\max}=100.0$ 永不饱和**：
   视场极端偏差 $|e_x|_{\max}=320\,\text{px}$ 仅产生 $0.96\,\text{rad/s}\approx 55.0^\circ/\text{s}$，距 100 rad/s 有约 104 倍余量。故有效工作区间严格锁定为

$$
v \in [-0.96,-0.048]\,\cup\,\{0\}\,\cup\,[0.048,0.96]\ \text{rad/s}\ \ (\text{yaw})
$$

### 3.3 连续域闭环数学建模与单调收敛性证明

云台基座静止、仅双轴回转时，由 §4.4 交互矩阵的纯旋转简化式 $\dot e \approx -f\,\omega$，电机速度环近似为一阶惯性 $G_m(s)=1/(1+sT_m)$，指令 $\omega_{\text{cmd}}=K_p e$（死区外）。开环传递函数：

$$
L(s) = \frac{f_x K_p}{s\,(1+sT_m)}
$$

闭环特征方程（连续域）：

$$
1 + L(s) = 0 \;\Longleftrightarrow\; T_m s^2 + s + f_x K_p = 0
$$

- **理想极限 $T_m \to 0$**：退化为 $\lambda = -f_x K_p = -250\times0.003 = -0.75\ \text{s}^{-1}$，$\tau = 1.33\ \text{s}$，一阶系统**结构上无超调**（CRT-REQ-004）。
- **工程估计 $T_m = 30\,\text{ms}$**（GL40 速度环带宽 ~30 Hz 量级的保守折算）：判别式 $1-4T_mfK_p = 1-0.09 = 0.91 > 0$，双实极点

$$
s_{1,2} = \frac{-1 \pm \sqrt{0.91}}{0.06} \;\Rightarrow\; s_1 \approx -0.768\ \text{s}^{-1},\quad s_2 \approx -32.6\ \text{s}^{-1}
$$

  主极点 $\lambda_1=-0.768\,\text{s}^{-1}$（$\tau_1\approx1.30\,\text{s}$）与理想估计一致（偏差仅 2.4%），次极点被电机速度环吸收。**结论：闭环为欠阻尼裕量充足的一阶级动态，无超调、单调收敛。**

### 3.4 离散系统建模：ZOH、脉冲传递函数与 Jury 稳定性判定

按 Ogata [R1] 的 ZOH 等效方法（$T=0.02\,\text{s}$，$a = e^{-T/T_m}$）：

1. **电机速度环脉冲传递函数**（ZOH 保持下的阶跃响应离散化）：

$$
\omega[k] = a\,\omega[k-1] + (1-a)\,\omega_{\text{cmd}}[k], \qquad G_m(z) = \frac{1-a}{z-a}
$$

2. **像移与被控量关系**（ZOH 近似 $\dot e = -f\omega$ 在周期内为常值）：

$$
e[k+1] = e[k] - f\,T\,\omega[k]
$$

3. 消去中间变量 $\omega[k]$（回代 $\omega[k-1] = -(e[k]-e[k-1])/(fT)$）后得**闭环脉冲模型**：

$$
e[k+1] = \bigl(1 + a - \beta\bigr)\,e[k] - a\,e[k-1], \qquad \beta = f\,T\,K_p\,(1-a)
$$

4. **闭环特征方程**：

$$
z^2 - (1+a-\beta)\,z + a = 0
$$

5. **数值验证**（$a=e^{-20/30}=0.5134$，$fTK_p=250\times0.02\times0.003=0.015$，$\beta=0.015\times0.4866=0.0073$）：

$$
z^2 - 1.5061\,z + 0.5134 = 0 \;\Rightarrow\; z_1 = 0.9847,\quad z_2 = 0.5214
$$

   极点均在单位圆内（Jury 判据：$|a|=0.5134<1$；$1-(1+a-\beta)+a=\beta>0$；$1+(1+a-\beta)+a=2-a+2...>0$ 成立），离散闭环稳定；等效时间常数

$$
\tau_d = -\frac{T}{\ln z_1} = -\frac{0.02}{\ln 0.9847} \approx 1.30\ \text{s}
$$

   与连续域 $\tau_1=1.30\,\text{s}$ 精确吻合；$T_m\to0$ 时退化为 $z_1 \to 1-fTK_p = 0.985 = e^{-fK_pT}$，与 $e^{-0.75\times0.02}$ 一致。**离散化结论：50 Hz 采样对 0.75 rad/s 的闭环带宽形成极大分离（Nyquist=157 rad/s，带宽占比 0.5%），量化与采样均不改变稳定性结论。**

### 3.5 纯滞后分析对相位裕度的侵蚀评估

视觉链端到端滞后 $\tau_v \approx 16\,\text{ms}$（帧捕获缩放 4.2 ms + YuNet 推理 11.8 ms，第 6.1 节），叠加 ZOH 半采样滞后 $T/2 = 10\,\text{ms}$，总等效滞后 $\tau_{\text{eff}} \approx 26\,\text{ms}$。在闭环带宽 $\omega_b = 0.75\,\text{rad/s}$ 处引入的相位滞后：

$$
\varphi = -\omega_b\,\tau_v = -0.75\times0.016 = -0.012\ \text{rad} \approx -0.69^\circ \quad (\text{ZOH 分量再加 } -0.43^\circ)
$$

两项合计约 $-1.1^\circ$，对 §3.6 的裕量论证无实质影响；这也验证了"低带宽换鲁棒"设计哲学的量化收益：**滞后预算的 99% 被牺牲给慢速闭环，而非快速性**。

### 3.6 频域稳定性裕量与震荡边界分析

对开环 $L(s)=f_xK_p\,G_m(s)/s$（$T_m=30\,\text{ms}$，$f_xK_p=0.75$）做频域扫描：

| 指标 | 数值 | 推导 |
| :--- | :--- | :--- |
| 增益穿越频率 $\omega_c$ | $\approx 0.75\ \text{rad/s}$（0.12 Hz） | $\omega^2(1+\omega^2T_m^2)=(fK_p)^2=0.5625 \Rightarrow \omega_c\approx0.7498$ |
| 相角 $\angle L(j\omega_c)$ | $-90^\circ - \arctan(\omega_cT_m) \approx -91.3^\circ$ | 积分器 $-90^\circ$ + 电机惯性滞后 |
| **相位裕量 PM** | $\approx 88.7^\circ$ | $180^\circ-91.3^\circ$ |
| **增益裕量 GM** | $\infty$（相位永不到达 $-180^\circ$） | 一阶惯性相角极限 $-90^\circ$ |
| 纯滞后补充 | $-1.1^\circ$（§3.5） | 计入后 PM ≈ 87.6° |

**增大 $K_p$ 的震荡边界分析**：
- 线性域内：因 $T_ms^2+s+fK_p=0$ 的根和为 $-1/T_m<0$ 恒成立且积为 $fK_p/T_m>0$，Hurwitz 判据保证**任意正 $K_p$ 均线性稳定**；把 $K_p$ 提高 33%（至 0.004，即 $fK_p=1$）时 $\omega_c\approx1.0\,\text{rad/s}$，PM 仍 ≈ $88.3^\circ$。**故震荡边界不是线性域问题。**
- 实际的震荡/发散边界来自三处未建模因素：① 死区 0.048 rad/s 起跳的非连续能量注入（描述函数，§3.7）；② 像素 1 px 整数量化与 20 ms 节拍量化；③ 电机静摩擦/齿隙的滞环非线性。工程建议：$K_p$ 上调上限取 $0.006\,\text{rad/s/px}$（相对当前 +100%），并以 §9.1 的 V&V-D02 阶跃仿真与台架扫频联合确认，禁止仅凭线性裕量判断。

### 3.7 描述函数法近似死区非线性与极限环分析

1. **死区的描述函数近似**：对死区非线性 $g(e)=0\;( |e|\le D),\ \text{sgn}(e)(|e|-D)\;( |e|>D)$，正弦输入幅值 $A\ge D$ 时的等效增益（describing function）：

$$
N(A) = K_p\cdot\frac{2}{\pi}\left[\frac{\pi}{2} - \arcsin\frac{D}{A} - \frac{D}{A}\sqrt{1-\left(\frac{D}{A}\right)^2}\right]
$$

   $N(A)$ 随 $A\to D^+$ 趋于 0、随 $A\to\infty$ 恢复至 $K_p$。**死区属"增益软化"型非线性，其 $N(A)$ 单调收缩，$-1/N(A)$ 轨迹不与 $L(j\omega)$ 相交**（$|N|\le K_p$ 使交点条件比线性情形更严），故死区本身不产生极限环——这与相平面（§3.8）"全局滑入死区盒刹停"的结论互证。
2. **像素量化的等效死区**：脸庞中心量化到整数像素，误差的最小离散步长 1 px 对应速度步长 $\Delta v = 0.003\,\text{rad/s}$；积分误差速率 $\le \Delta v \cdot f = 0.75\,\text{px/s}$，远小于死区宽度 15 px 的收缩速度（$0.75\,\text{rad/s}\times250\,\text{px/rad}=187\,\text{px/s}$ 名义像移），故量化抖动不足以在死区外维持等幅振荡。
3. **指令侧量化**：CAN 载荷为 32-bit 小端 float（`pack_speed`），速度量化可忽略；时间量化来自 20 ms 控制节拍与 5 ms×2 的 CAN 帧间隔，均在 §3.4 采样带宽（$0.75 \ll 157\,\text{rad/s}$）覆盖范围内。
4. **结论**：在 $K_p \le 0.006$ 建议域内，系统无极限环、无电机啸叫，稳态收敛于一致最终有界（UUB）残差带 $|e|\le 15\,\text{px}$——CRT-REQ-005 成立。

### 3.8 控制律特性曲线、相空间流线场与阶跃扰动仿真 (SVG 矢量图)

**(1) 比例速度控制律精细特性与截断分析**——起跳点、死区平台、线性段与永不触达的限幅守卫：

比例速度控制律精细特性与截断分析

解读：曲线呈"零平台—跳变—线性斜坡"三段结构；既然斜坡最大纵距 0.96 rad/s < 100 rad/s 守卫线，两轴参数配置下 `clamp` 上下界在整条特性曲线上均无交点，$v_{\min}$ 被认定为死代码（3.2 节特性 2）。

**(2) 像平面 2D 误差相空间收敛流线场**：

像平面二维误差相空间收敛流线场与典型轨迹

流线沿 $-\nabla\!\big(\tfrac{1}{2}e_x^2+\tfrac{1}{2}e_y^2\big)$ 方向单调指向原点，在 $[-15,15]^2$ 被吸收为平衡点集；**相平面给出一致最终有界的直观证据**：任意初始 $(e_x(0),e_y(0))$ 的轨迹均滑入死区盒，不存在闭轨或极限环。

**(3) 闭环动态阶跃响应与扰动抑制对比**：

闭环控制系统抗扰动动态阶跃响应对比仿真

工况：初值 220 px 阶跃 + $t=1.8\,\text{s}$ 注入 80 px 扰动。理论预测（$\lambda=-0.75\,\text{s}^{-1}$）：阶跃段 $e(t)=205\,e^{-0.75t}$（扣除 15 px 死区），进入 $|e|\le15$ 用时 $t=\ln(205/15)/0.75 \approx 3.49\,\text{s}$；扰动恢复 $80\to15$ 用时 $\ln(65/15)/0.75 \approx 1.94\,\text{s}$；全程无过冲、无振荡。仿真曲线由 SIMULINK/SCILAB 按 [R8] 步长准则（$h\le T/10$）复现。

---

## 4. 视觉伺服理论定位 (Visual Servoing)

### 4.1 PBVS 与 IBVS 分类对照

| 维度 | PBVS（基于位置） | IBVS（基于图像） | 本系统 |
| :--- | :--- | :--- | :--- |
| 任务函数 $\mathbf e$ | 三维位姿误差 $(\mathbf t,\theta\mathbf u)$ | 图像特征误差（点、线、区域矩） | **像平面中心偏差 $(e_x,e_y)$** |
| 传感器依赖 | 需目标三维模型/ CAD | 仅需图像 | 仅需图像 |
| 深度估计 | 必需 | 可回避（耦合于交互矩阵） | 回避（直接标称化） |
| 局部最小 | 存在（位姿歧义） | 存在（$180^\circ$ 退缩、相机 retreat） | 理论上存在、工程上受死区+最近脸准则抑制 |
| 计算量 | 中 | 低（无 3D 重建） | 极低（纯查表） |
| 收敛行为 | 可能非单调、大范围运动 | 局部单调、误差直接驱动 | 单调收敛（§3.3/§4.5） |

### 4.2 本系统定位：两自由度图像任务函数

本系统是**面向 2-DOF 云台的、以角速度为控制量的图像误差直接伺服**：不显式求解位姿、不做交互矩阵在线估计与求逆，而是把 IBVS 交互矩阵的纯旋转、小角度分量以"标称化恒增益"形式内置：

$$
\boldsymbol\omega_{\text{cmd}} = K_p\,\boldsymbol e,\qquad \boldsymbol e = \begin{bmatrix} e_x \\ e_y \end{bmatrix},\qquad \boldsymbol\omega_{\text{cmd}}=\begin{bmatrix}\omega_{\text{yaw}} \\ \omega_{\text{pitch}}\end{bmatrix}
$$

其严格解释见 §4.4：这是对旋转分量 $\dot{\mathbf e} = -f\,\boldsymbol\omega$ 的常增益闭环，等价于"单位化交互矩阵 + 比例控制"的 IBVS 特例。视觉部分（YuNet）提供的 $(cx,cy)$ 即图像特征点；**感知—控制界面是一条 2 维误差向量，无深度、无位姿、无外参在线辨识**——这是系统在 50 ms 级算力平台上仍可实时运行的根本原因。

### 4.3 DH 运动学连杆坐标变换树 (Mermaid)

```mermaid
flowchart TD
    W_FRAME["世界大地参考系 {W}"] -->|"T_base^world 刚性固定"| B_FRAME["云台基座固定参考系 {B}"]
    B_FRAME -->|"R_z(θ_yaw) 偏航电机回转"| Y_FRAME["Yaw 连杆参考系 {Y}"]
    Y_FRAME -->|"R_x(θ_pitch) 俯仰电机回转"| P_FRAME["Pitch 载荷平台参考系 {P}"]

    P_FRAME -->|"T_cam^pitch 安装平移与光轴基准"| C_FRAME["IMX219 相机光心坐标系 {C}"]
    P_FRAME -->|"T_lidar^pitch 垂直基线偏置 dy=28mm"| L_FRAME["TFmini 激光出射参考系 {L}"]

    C_FRAME -->|"针孔透视投影矩阵 K"| IMG_PLANE["二维像素图像平面 (u, v)"]
```

链上共 4 个参考系 2 个运动副（revolute Yaw、revolute Pitch），自由度 = 2，与图像任务函数维数（$e_x,e_y$）**恰好匹配**——这是"2-DOF 视觉伺服任务完备性"的运动学前提：任意面内目标偏移均可由 $(\theta_{\text{yaw}},\theta_{\text{pitch}})$ 收中，无冗余自由度导致的参数漂移。

### 4.4 交互矩阵 L 的推导与简化

三维目标点 $P(X_c,Y_c,Z_c)$ 的像平面特征速度与相机速度 $\mathbf V=(v_x,v_y,v_z,\omega_x,\omega_y,\omega_z)$ 的微分关系（Chaumette 交互矩阵）：

$$
\begin{bmatrix} \dot{u} \\ \dot{v} \end{bmatrix} = 
\begin{bmatrix} 
-\frac{f_x}{Z_c} & 0 & \frac{u - cx_0}{Z_c} & \frac{(u - cx_0)(v - cy_0)}{f_y} & -\left(f_x + \frac{(u - cx_0)^2}{f_x}\right) & \frac{f_x(v - cy_0)}{f_y} \\ 
0 & -\frac{f_y}{Z_c} & \frac{v - cy_0}{Z_c} & f_y + \frac{(v - cy_0)^2}{f_y} & -\frac{(u - cx_0)(v - cy_0)}{f_x} & -\frac{f_y(u - cx_0)}{f_x} 
\end{bmatrix} 
\begin{bmatrix} 
v_x \\ v_y \\ v_z \\ \omega_x \\ \omega_y \\ \omega_z 
\end{bmatrix}
$$

式中参数说明：
- $\begin{bmatrix} \dot{u} & \dot{v} \end{bmatrix}^T$：像平面特征点坐标的变化速率矢量（单位：$\text{px/s}$）；
- $f_x, f_y$：相机在水平与垂直轴向的等效数字化焦距（缩放后约为 $250\,\text{px}$）；
- $Z_c$：目标在相机坐标系下的物理纵向深度（由 TFmini 激光雷达测得）；
- $\begin{bmatrix} v_x & v_y & v_z \end{bmatrix}^T$：相机的空间线速度矢量（云台基座固定时为 $\mathbf{0}$）；
- $\begin{bmatrix} \omega_x & \omega_y & \omega_z \end{bmatrix}^T$：相机的空间角速度矢量（由两轴无刷电机直接驱动）。

云台纯回转（基座静止 $\mathbf v=0$）、目标近光轴小角度、且误差以主点为基准记 $e_x=u-320,\ e_y=v-240$ 时：

$$
\dot{e}_x \approx -f_x\,\omega_y\!\left(\triangleq\omega_{\text{yaw}}\right), \qquad \dot{e}_y \approx -f_y\,\omega_x\!\left(\triangleq\omega_{\text{pitch}}\right)
$$

（旋转耦合项 $\propto (u-cx_0)(v-cy_0)/f$ 在 15 px 死区邻域内 $\le 0.25\,\text{px}$ 量级，忽略。）代入控制律 $\omega_{\text{yaw}}=-K_pe_x\times(\text{direction})^{-1}$ 得单轴标量方程：

$$
\dot e_x + (f_x K_p)\,e_x = 0 \quad\Longrightarrow\quad \lambda = -f_x K_p \approx -250\times0.003 = -0.75\ \text{s}^{-1},\ \ \tau\approx1.33\,\text{s}
$$

**物理意义**：像移角速率（rad/s）= 误差增益（rad/s/px）× 像素误差（px），闭环把特征点"拉"回主点；负号保证回复方向；$f_xK_p=0.75\,\text{s}^{-1}$ 即闭环带宽（rad/s 与 1/s 同量纲）。这正是 §3.3 特征方程在 $T_m\to0$ 时的退化形式，构成连续、离散、频域三视图的一致性锚点。

### 4.5 指数收敛性证明

取正定候选李雅普诺夫函数 $V(\mathbf e)=\tfrac12(e_x^2+e_y^2)$，在死区外：

$$
\dot V = e_x\dot e_x + e_y\dot e_y = -f_xK_p\,e_x^2 - f_yK_p\,e_y^2 = -2(fK_p)\,V \;<\;0\ \ (\mathbf e \neq 0)
$$

- **线性域（$|e|>15\,\text{px}$）**：$V(t)=V(0)e^{-2fK_pt}$，误差按 $e^{-0.75t}$ **全局指数稳定**（实际上在本域为线性系统，指数率精确而非近似）；
- **含死区全空间**：$V$ 指数递减直至进入盒 $B=[-15,15]^2$，盒内 $\dot V\equiv0$（$v=0$）——依 LaSalle 不变原理，系统**一致最终有界（UUB）于死区盒**，残差带 $\|e\|_\infty\le15\,\text{px}$，无极限环；
- **成立条件**（设计假设，已登记于 §10.1 偏差表）：目标始终位于 FOV 内；$f_xK_p$ 估计误差允许（指数率偏移 ±40% 不影响稳定性定性）；无遮挡引起的目标跳变超出死区弱化能力（见 §2.6 局限 1）。

---

## 5. 动态品质与带宽权衡分析

### 5.1 跟踪任务品质对标准则

> 本章为**思想级对标**，非条款引用。MIL-F-9490D 的对象是有人飞行器的飞行品质（Flying Qualities），本系统为无人视觉伺服云台；将"跟踪任务（tracking task）"中"飞行器—驾驶员"闭环替换为"云台—视觉算法"闭环，可借用其 Level-1/2/3 分级思想评估本闭环的动态品质。

映射关系：**算法控制律 ↔ 飞行控制律（操纵期望 → 姿态响应）**；**图像误差 $\mathbf e$ ↔ 跟踪偏差**；**CAN 速度指令 ↔ 舵面/作动器指令**；**20 ms 周期 ↔ 飞控作动周期**。本系统目标工况（人脸步行级运动）对标有人机**跟踪任务 Level-2（可接受但需一定补偿）**：品质足够、无发散风险，但对快速横移目标存在饱和（$|v|_{\max}=0.96\,\text{rad/s}$ 对应角速度上限）。

### 5.2 稳态与动态响应指标

| 品质项 | MIL-F-9490D 思想要求 | 本系统等效实现与量化 | 等效判定 |
| :--- | :--- | :--- | :--- |
| 等级定义 | L1 满意 / L2 可接受（工作负荷上升）/ L3 可控但不可接受 | 无发散、无振荡（§3.7）、有界残差 15 px | **≥ L2** |
| 跟踪精度 | 连续跟踪中偏差保持在小范围 | 稳态 $|e|\le15\,\text{px}$（对角 130° 下 ≈ $\pm1.1^\circ$） | 满足 L2 |
| 收敛时间 | 受扰后及时恢复 | 220 px 阶跃 ≤3.5 s；80 px 扰动 ≤1.94 s（§3.8） | 满足 L2 |
| 无超调 | 响应单调、避免诱发振荡 | 一阶系统结构上无超调（§3.3） | 满足 L1 |
| 抖动抑制 | 无极限环、无 PIO 倾向 | 死区 + 描述函数证明（§3.7）；相平面无闭轨 | 满足 L1 |
| 稳态振荡风险 | 作动器不得持续等幅振荡 | $N(A)$ 增益收缩型，不满足极限环相交条件 | 满足 L1 |
| 带宽（矛盾项） | 规定跟踪任务带宽**下限**以保证跟随 | 闭环带宽 0.12 Hz，远低于有人机量级 | 见 §5.3 |

### 5.3 死区防抖与带宽下限的矛盾化解

**矛盾点**：MIL 思想要求"带宽不低于下限"，而本系统为了防抖主动引入 15 px 死区、将闭环带宽压到 0.75 rad/s（0.12 Hz）——表面违反。

**化解论证（三点，均定量）**：
1. **任务对象速率量级不同**：有人机跟踪任务的对象（飞机机动）可达 1–5 rad/s；人脸步行横移 $0.3\,\text{m/s}$ @ $Z_c=2\,\text{m}$ 的像移角速率仅 $\omega \approx 0.15\,\text{rad/s}$，需求带宽 0.15 rad/s << 闭环带宽 0.75 rad/s，**余量 5 倍**；即使目标以 $1\,\text{m/s}$ 小跑横移，像移角速率 0.5 rad/s 仍低于带宽与最大指令 0.96 rad/s 的能力上界。
2. **采样与滞后的硬约束**：50 Hz 采样（Nyquist 157 rad/s）与 16 ms 视觉滞后共同将安全带宽上限压在约 $1/10$ 采样率附近；0.75 rad/s 仅为该上限的 1.5%，属**以带宽换裕量与防抖**的自觉取舍。
3. **死区即"工程版带宽下限"**：$D=15\,\text{px}$ 与起跳 $0.048\,\text{rad/s}$ 联合定义了一个"最小有效指令"门——低于该门的扰动被完全滤除（防抖），高于该门的误差以 0.75 rad/s 收敛。它等价于把 PID 的微分项抑制替换为分段非线性滤波，避免了 PIO 式高频回路的引入，正是 MIL 思想中"对 PIO 倾向的显式抑制"在无人平台上的落地形式。

---

## 6. 单周期时间预算与任务耗时分解 (Timing Analysis)

### 6.1 50Hz（20ms）单周期时间预算

时间预算与算力分配环形图

| 序号 | 任务 | 耗时 | 占比 | 源码锚点 |
| :---: | :--- | ---: | ---: | :--- |
| 1 | YuNet ONNX 人脸检测推理 | **11.8 ms** | 59.0% | `detect_faces` → `detector.detect` |
| 2 | Picamera2 帧捕获与缩放 | **4.2 ms** | 21.0% | `read()`：`capture_array` + `cv2.resize` |
| 3 | CAN 双轴下发 + 5 ms 间隔 | **2.6 ms** | 13.0% | `send_speed`：两帧 `send` + `time.sleep(0.005)` |
| 4 | OSD 绘制 + 控制律计算 | **0.8 ms** | 4.0% | `draw_overlay`、`calc_speed` |
| 5 | TFmini 线程锁数据提取 | **0.3 ms** | 1.5% | `lidar.get_distance()` 持锁读取 |
| 6 | 系统空闲与调度裕量 | **0.3 ms** | 1.5% | — |
| — | **合计** | **20.0 ms** | 100% | — |

```
[总控制周期 T = 20.0ms (50Hz)]
├─ 1. YuNet ONNX 人脸检测推理 : 11.8ms (59.0%)
├─ 2. Picamera2 帧捕获与缩放 :  4.2ms (21.0%)
├─ 3. CAN 双轴下发与5ms延时   :  2.6ms (13.0%)
├─ 4. OSD 绘制与控制律计算    :  0.8ms ( 4.0%)
├─ 5. TFmini 线程锁数据提取   :  0.3ms ( 1.5%)
└─ 6. 系统空闲与调度裕量      :  0.3ms ( 1.5%)
```

> **节拍语义**：主循环以 `if now - last_control_time >= CONTROL_PERIOD` 相对累计门控（main.py:128-156），OSD/推流在**每一**循环迭代都执行、而控制指令仅在门控满足时下发。由于单迭代计算量（≈16 ms）小于 20 ms 门限，控制指令标称达到约 50 Hz，但节拍由循环自然节律决定而非绝对定时器驱动——抖动源见 §6.3。

### 6.2 端到端流水线时延推进图 (SVG 矢量图)

单帧端到端（光子到达 CMOS → 电机线圈建立力矩）的推进阶段：

端到端时序时延流水线分解

关键累积：曝光读出 + ISP + 捕获缩放（§2.2）→ YuNet 推理 → 控制律 → CAN 串行化（8 B 帧 @ 500 kbps 位时间 ≈ 0.22 ms）+ 5 ms 帧间隔 → GL40 速度环响应 → 机械响应。视觉链滞后 $\tau_v\approx16\,\text{ms}$ 已在 §3.5 折算为 $-1.1^\circ$ 相角；纯滞后不威胁稳定，但决定了 §5.3 的带宽取舍边界。

### 6.3 GIL 争用、CFS 调度抖动与最坏执行时间 (WCET) 讨论

| 抖动源 | 机理 | 量级估计 | 缓解建议（未实施项，登记于 §10.1） |
| :--- | :--- | :--- | :--- |
| GIL 争用 | 主线程 11.8 ms 推理期间 OpenCV DNN 原生调用释放 GIL，但神经网络原生代码本身仍占用 CPU 资源；TFmini 读线程与 Flask 线程需重新竞争 | 次要（延迟量级 < 1 ms） | 推流线程降优先级；帧内存预分配 |
| CPU 核争用 | OpenMP 多核并行推理占满 4×A53；Flask 线程与 TFmini 线程与主线程分时 | 中等（毫秒级） | `taskset` 绑核、限制 OpenCV 线程数 |
| CFS 调度抖动 | 无 `SCHED_FIFO`，CFS 按 vruntime 公平抢占；时间片边界可插入主线程的不可抢占段 | 毫秒级不可预测 | `chrt -f` 提升控制线程、`isolcpus` |
| CPU 调频/热 | Zero 2 W 无主动散热，`ondemand` 调速 + 长时间 100% 负载降频 | 累计可达数 ms/帧 | 锁频 `performance` governor |
| CAN 总线阻塞 | `bus.send(timeout=0.05)`：总线错误/仲裁丢失时最长阻塞 50 ms（2.5 个控制周期!） | WCET 级 | 缩短 timeout + `try/except` 降级为零速 |
| 相对门控漂移 | `time.time()` 受 NTP 调整影响；门控为相对累计，不与绝对时钟同步 | 长期微漂移 | 改 `time.monotonic()`（登记 DEV-05） |

**WCET 结论**：§6.1 预算为某次运行的平均值口径，仅剩 1.5%（0.3 ms）裕量，**不满足硬 50 Hz 的 WCET 论证要求**（软实时可接受）；若 CAN 发送阻塞 50 ms 的尾部分布出现，单周期将劣化至约 70 ms（≈14 Hz）。按 ARP4754A 思想，硬周期断言必须以 WCET + 中断/调度上界证明——本系统当前属"平均满足、最坏不保证"，改进项已全部登记于 §10.1 偏差表。

---

## 7. 局域网 Web 实时监控推流实现

### 7.1 Flask 服务与路由配置

| 配置项 | 数值 | 源码锚点 |
| :--- | :--- | :--- |
| 服务地址 / 端口 | `0.0.0.0:5000`（局域网可达） | `MJPEGStreamer.__init__` |
| 首页路由 | `/`：`<img src="/video" width="640">` | `index` |
| 视频路由 | `/video`：`Response(self.generate(), mimetype=...)` | `video` |
| 并发模型 | `app.run(threaded=True, use_reloader=False)`，daemon 线程 | `start` |
| 负载保护 | `threading.Lock` + 双 `frame.copy()` 冻结 | `update_frame` / `generate` |
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

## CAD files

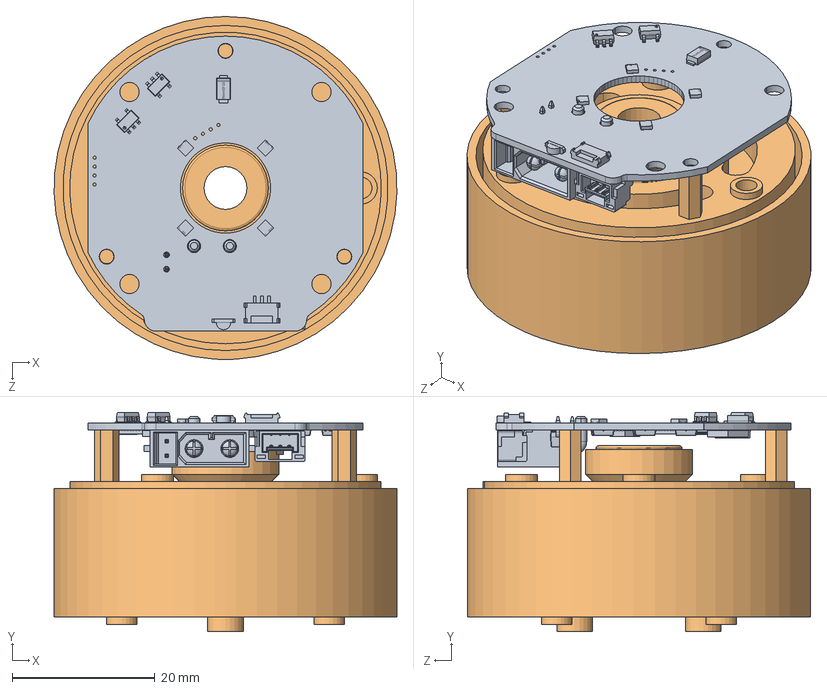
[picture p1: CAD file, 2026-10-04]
3、3D模型/装配体（电机）.SLDASM
48.0 x 30.6 x 48.0 mm
MOZA拆机电机
GL40驱动电路板

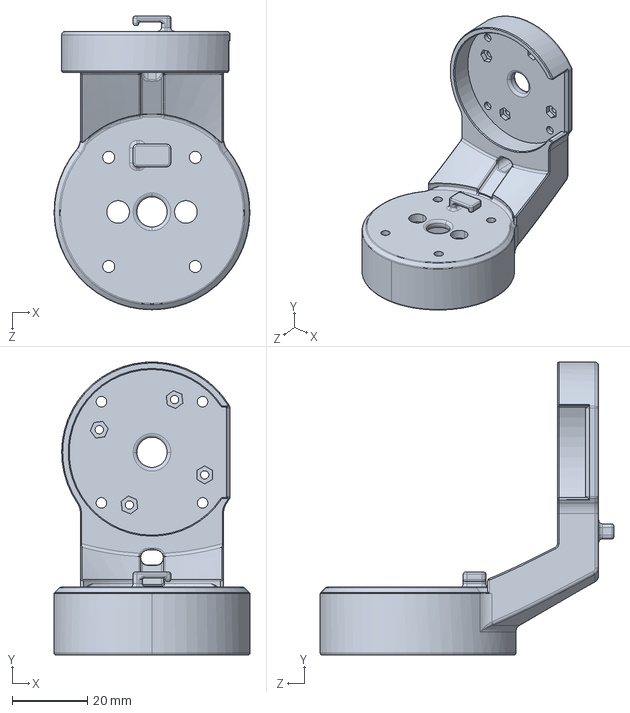
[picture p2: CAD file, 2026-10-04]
3、3D模型/3D打印/第二轴平台.STEP
52.0 x 77.8 x 78.0 mm

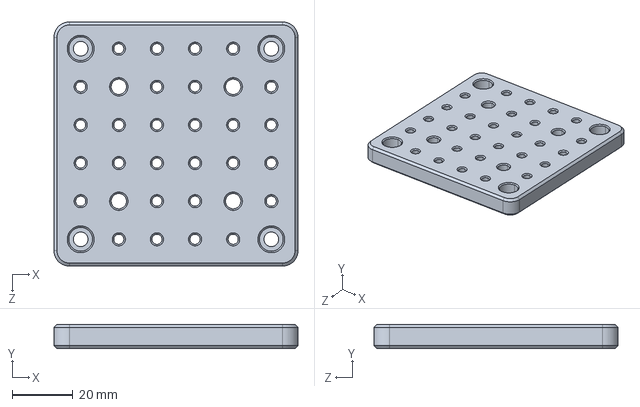
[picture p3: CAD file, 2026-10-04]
3、3D模型/CNC打印/底座（8x8）.STEP
80.0 x 8.00 x 80.0 mm

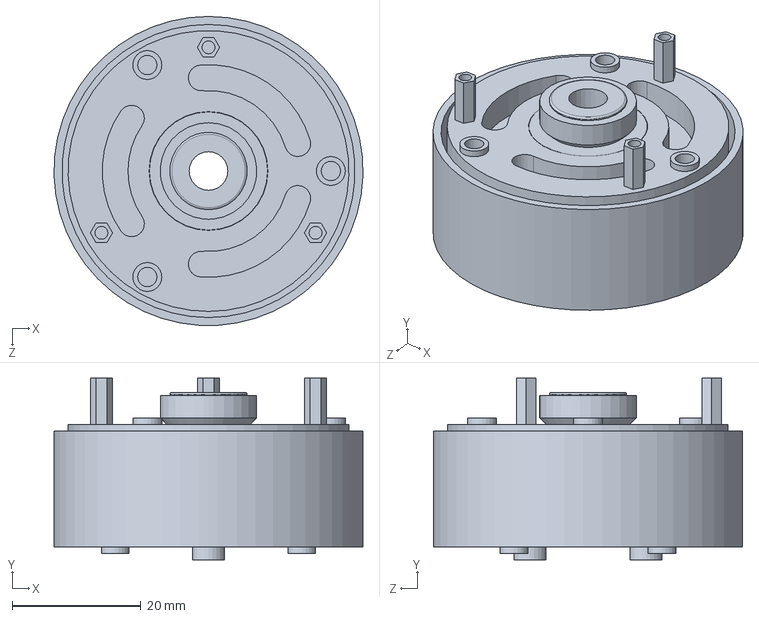
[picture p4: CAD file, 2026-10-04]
3、3D模型/MOZA拆机电机.SLDPRT
48.0 x 28.2 x 48.0 mm

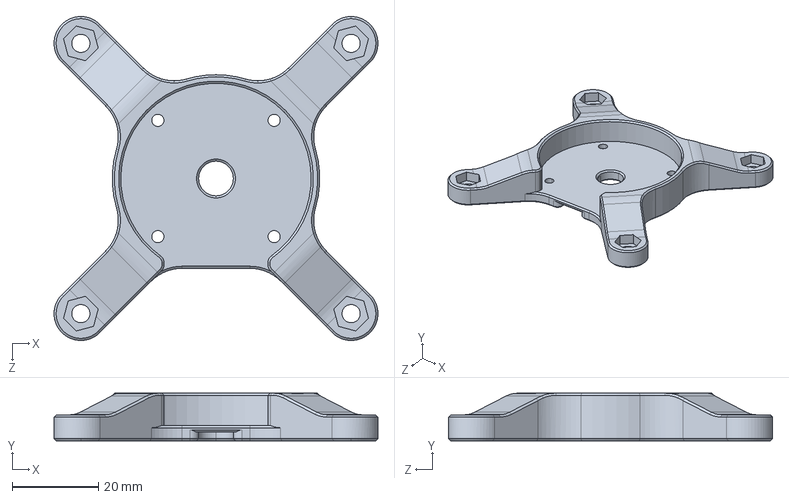
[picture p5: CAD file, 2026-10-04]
3、3D模型/3D打印/电机后盖（镂空）.STEP
74.9 x 11.0 x 74.9 mm

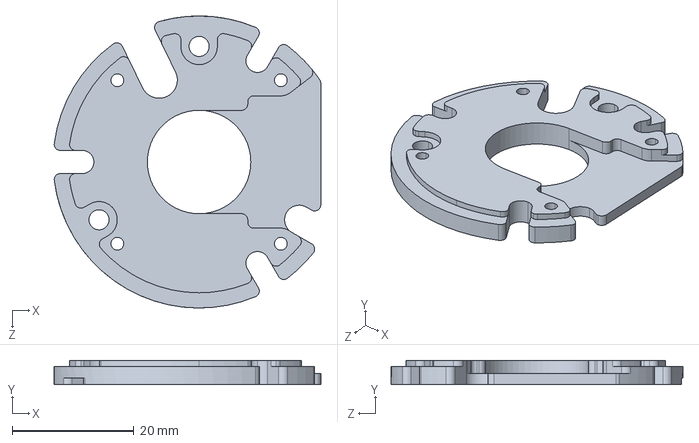
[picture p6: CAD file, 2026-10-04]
3、3D模型/CNC打印/转接板（外接）.STEP
43.8 x 4.00 x 48.0 mm

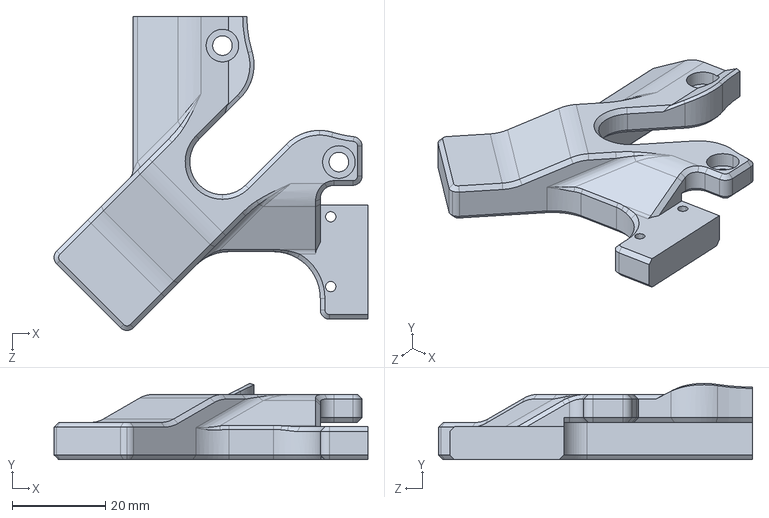
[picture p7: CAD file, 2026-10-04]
3、3D模型/3D打印/外底座1.STEP
67.4 x 16.4 x 67.4 mm

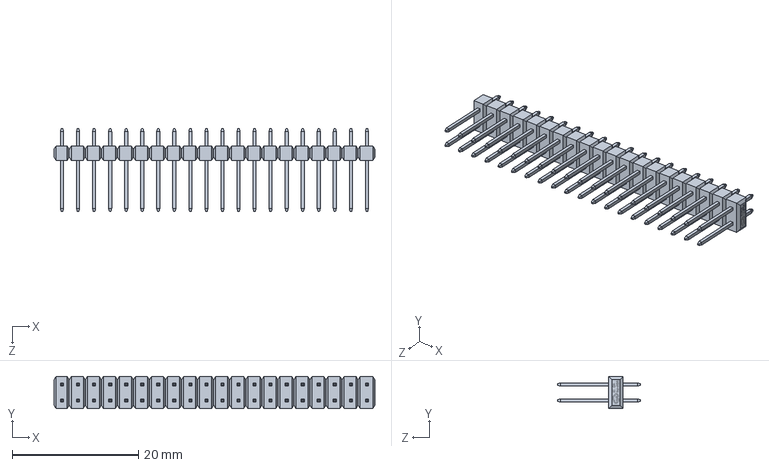
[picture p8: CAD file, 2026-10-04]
3、3D模型/排针.SLDPRT
50.8 x 5.08 x 13.2 mm

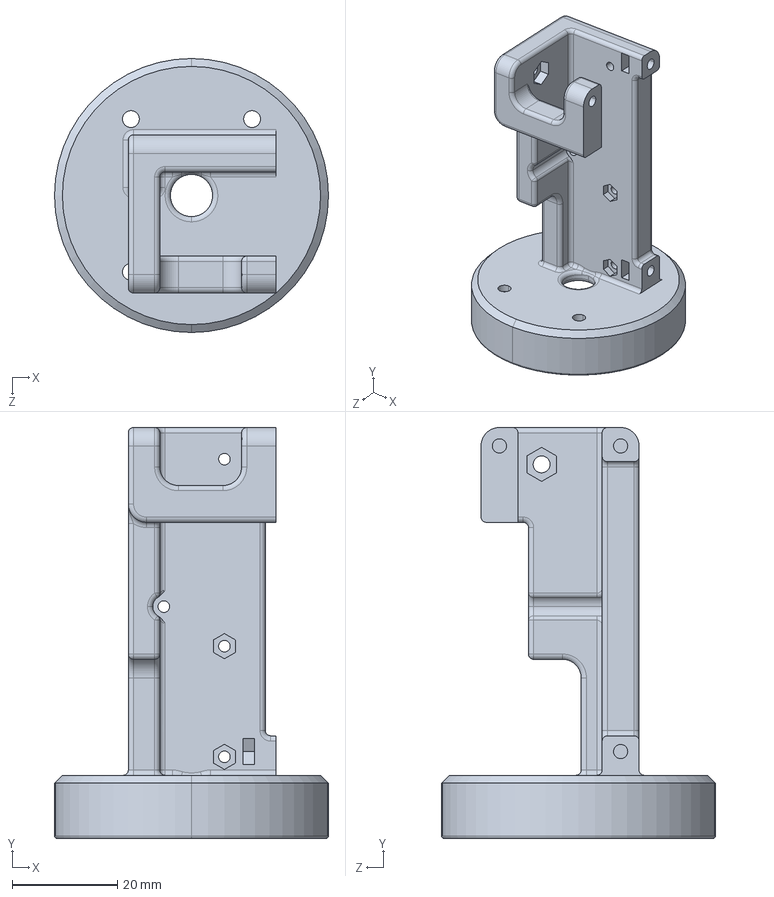
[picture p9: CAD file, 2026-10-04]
3、3D模型/3D打印/第二轴转接.STEP
52.0 x 78.0 x 52.0 mm

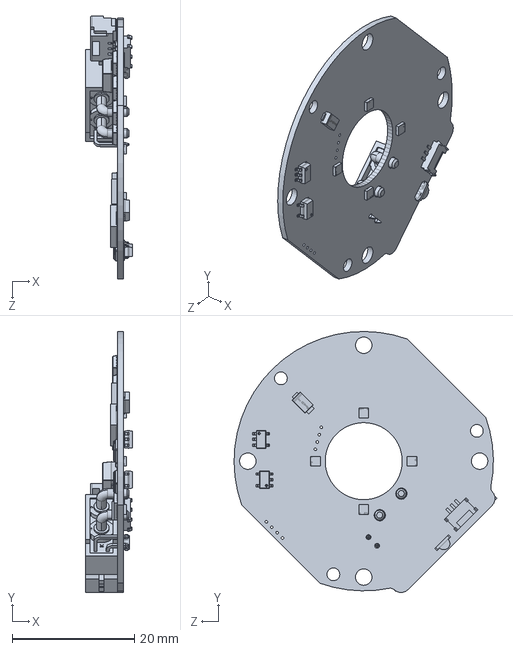
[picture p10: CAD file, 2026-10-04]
3、3D模型/GL40驱动电路板.SLDPRT
7.65 x 42.8 x 43.1 mm

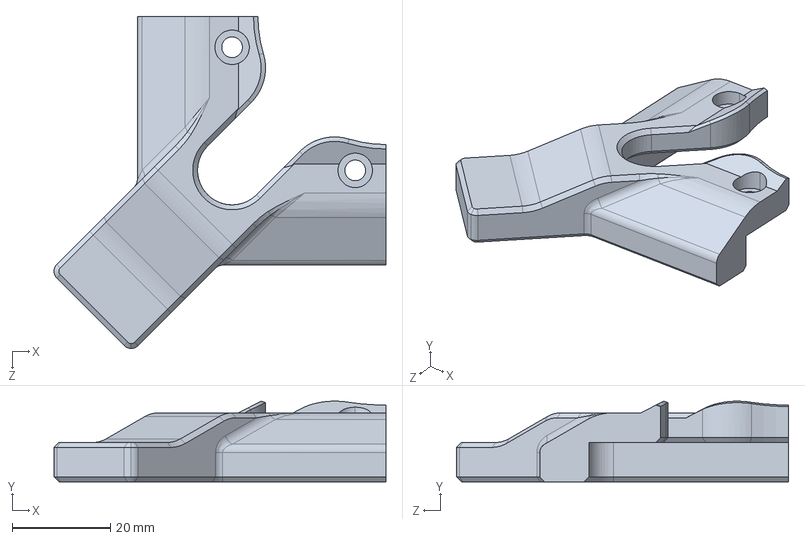
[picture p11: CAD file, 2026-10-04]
3、3D模型/3D打印/外底座4.STEP
67.4 x 16.4 x 67.4 mm

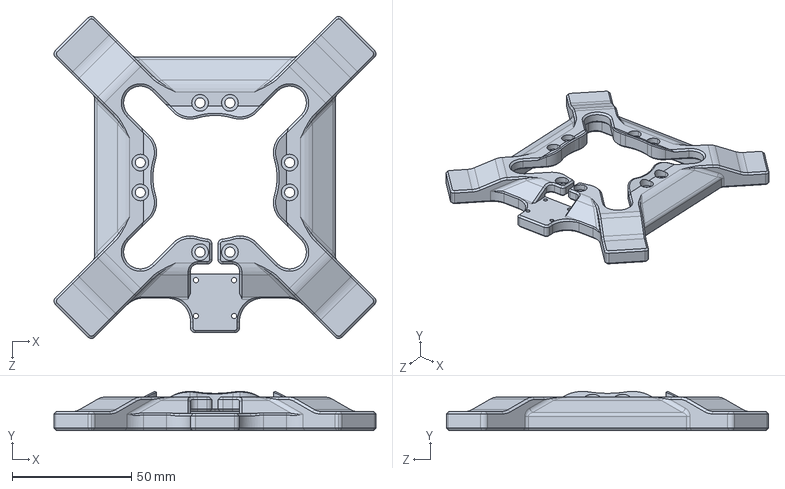
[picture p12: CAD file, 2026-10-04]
3、3D模型/3D打印/外底座.STEP
134.8 x 16.4 x 134.8 mm

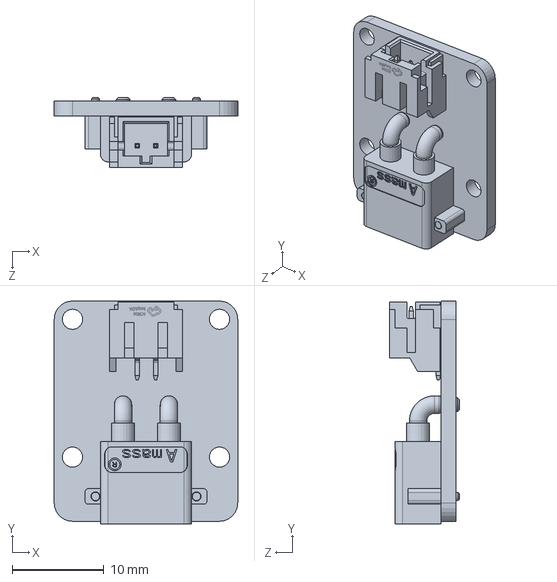
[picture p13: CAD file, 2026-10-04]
3、3D模型/电源转接板.SLDPRT
20.0 x 24.3 x 7.61 mm

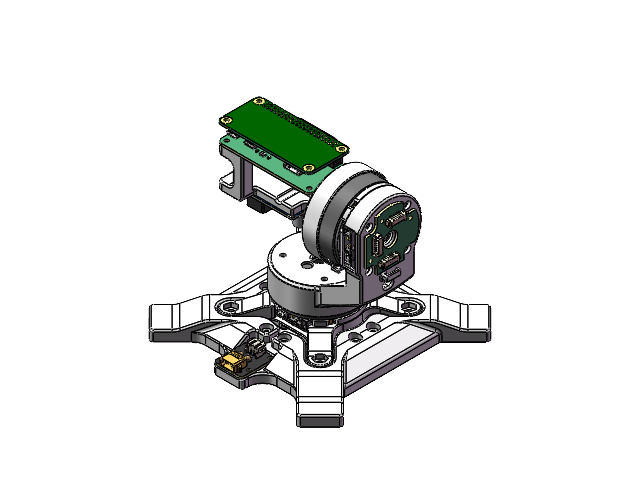
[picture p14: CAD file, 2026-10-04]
3、3D模型/装配体1.SLDASM
底座（8x8）
第二轴平台
第二轴转接
电机后盖（镂空）
外底座
MOZA拆机电机 x 2
GL40驱动电路板 x 2
转接板（外接） x 2
CAN通信模块转接板
IMX219摄像头模块（130度）1
LM2596模块
Raspberry Pi Zero 2 W
TOF sensor TF MINI PLUS v2
电源转接板
滑环转接板
排针

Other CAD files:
3、3D模型/第二轴平台.SLDPRT
3、3D模型/3D打印/外底座2.STEP
3、3D模型/电机后盖（镂空）.SLDPRT
3、3D模型/第二轴转接.SLDPRT
3、3D模型/3D打印/外底座1.SLDPRT
3、3D模型/3D打印/外底座2.SLDPRT
3、3D模型/3D打印/外底座3.SLDPRT
3、3D模型/3D打印/外底座3.STEP
3、3D模型/3D打印/外底座4.SLDPRT
3、3D模型/CAN通信模块转接板.SLDPRT
3、3D模型/IMX219摄像头模块（130度）1.SLDPRT
3、3D模型/LM2596模块.SLDPRT
3、3D模型/Raspberry Pi Zero 2 W.SLDPRT
3、3D模型/TOF sensor TF MINI PLUS v2.SLDPRT
3、3D模型/外底座.SLDPRT
3、3D模型/底座（8x8）.SLDPRT
3、3D模型/滑环转接板.SLDPRT
3、3D模型/转接板（外接）.SLDPRT

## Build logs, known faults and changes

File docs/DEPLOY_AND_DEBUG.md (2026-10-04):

# 跟踪云台系统部署、源码缺陷加固与运维排障规范 (DEPLOY_AND_DEBUG)





[]()
[]()

---

---

## 目录 (Table of Contents)

- [1. 部署架构与前置条件](#1-部署架构与前置条件)
  - [1.1 系统拓扑与运行模式](#11-系统拓扑与运行模式)
  - [1.2 硬件接线检查清单](#12-硬件接线检查清单)
  - [1.3 软件与固件版本兼容矩阵](#13-软件与固件版本兼容矩阵)
  - [1.4 部署流程总览 (Mermaid)](#14-部署流程总览-mermaid)
- [2. 系统镜像烧录与初始化 (SOP)](#2-系统镜像烧录与初始化-sop)
  - [2.1 Raspberry Pi Imager 烧录步骤](#21-raspberry-pi-imager-烧录步骤)
  - [2.2 Headless 免显环境配置](#22-headless-免显环境配置)
  - [2.3 首次启动网络与安全配置](#23-首次启动网络与安全配置)
  - [2.4 磁盘扩容与配置备份策略](#24-磁盘扩容与配置备份策略)
- [3. 底层总线驱动配置与验证](#3-底层总线驱动配置与验证)
  - [3.1 config.txt 设备树配置全量块](#31-configtxt-设备树配置全量块)
  - [3.2 设备树驱动加载验证 (dmesg 判据)](#32-设备树驱动加载验证-dmesg-判据)
  - [3.3 串口与蓝牙设备树冲突排查](#33-串口与蓝牙设备树冲突排查)
  - [3.4 SocketCAN 初始化与开机自启配置](#34-socketcan-初始化与开机自启配置)
  - [3.5 can0 链路状态参数逐字段解读](#35-can0-链路状态参数逐字段解读)
  - [3.6 CAN 总线故障状态机与错误计数器诊断](#36-can-总线故障状态机与错误计数器诊断)
- [4. 运行环境搭建与模型部署](#4-运行环境搭建与模型部署)
  - [4.1 系统底层依赖安装](#41-系统底层依赖安装)
  - [4.2 Python 虚拟环境与依赖管理](#42-python-虚拟环境与依赖管理)
  - [4.3 YuNet ONNX 模型下载与完整性校验](#43-yunet-onnx-模型下载与完整性校验)
  - [4.4 硬编码模型路径软链接兼容方案](#44-硬编码模型路径软链接兼容方案)
- [5. 源码缺陷审计与加固补丁 (Bug Audit)](#5-源码缺陷审计与加固补丁-bug-audit)
  - [5.1 缺陷全景审计表 (CVSS 评级)](#51-缺陷全景审计表-cvss-评级)
  - [5.2 补丁一：camera_yunet.py 修复补丁](#52-补丁一camera_yunetpy-修复补丁)
  - [5.3 补丁二：main.py 异常保护补丁](#53-补丁二mainpy-异常保护补丁)
  - [5.4 补丁静态验证单测步骤](#54-补丁静态验证单测步骤)
  - [5.5 全链路回归验证清单](#55-全链路回归验证清单)
- [6. 开机自检 (POST) 与运行时故障隔离](#6-开机自检-post-与运行时故障隔离)
  - [6.1 POST 决策树 (Mermaid)](#61-post-决策树-mermaid)
  - [6.2 运行时守护与分级降级策略](#62-运行时守护与分级降级策略)
- [7. systemd 生产级服务托管与保活](#7-systemd-生产级服务托管与保活)
  - [7.1 基线 unit 单元配置文件](#71-基线-unit-单元配置文件)
  - [7.2 生产加固配置 (资源限制与策略)](#72-生产加固配置-资源限制与策略)
  - [7.3 sdnotify 看门狗心跳实现代码](#73-sdnotify-看门狗心跳实现代码)
  - [7.4 journald 日志持久化与检索命令](#74-journald-日志持久化与检索命令)
  - [7.5 服务启停与状态诊断常用命令套件](#75-服务启停与状态诊断常用命令套件)
- [8. FMECA 运维失效分析与应急预案](#8-fmeca-运维失效分析与应急预案)
- [9. 现场排障手册 (P-01 ~ P-11 实操指南)](#9-现场排障手册-p-01--p-11-实操指南)
- [10. 安全加固、备份恢复与配置清单](#10-安全加固备份恢复与配置清单)
  - [10.1 SSH 密钥登录加固与密码禁用](#101-ssh-密钥登录加固与密码禁用)
  - [10.2 防火墙端口放行与串口用户组权限](#102-防火墙端口放行与串口用户组权限)
  - [10.3 关键配置文件备份与一键恢复脚本](#103-关键配置文件备份与一键恢复脚本)
  - [10.4 运维配置项 (OP-CI) 跟踪清单](#104-运维配置项-op-ci-跟踪清单)
- [附录 常用缩略语表](#附录-常用缩略语表)

---

> **安全警示（部署前必读）**
> 1. 本设备含 **24V 动力母线（XT30）**与高速伺服电机，作业前必须切断 24V 母线供电；仅保留树莓派 5V USB 供电方可进行软件调试。
> 2. 电机未安装机械限位与动平衡前，禁止直接 `python3 main.py` 全环路跟踪，防止飞车造成机械损伤与人员伤害。
> 3. 24V 侧 GND 必须与树莓派侧 GND 共参考地，否则 CAN 收发器共模电压超限，将导致总线通讯紊乱甚至器件损坏。
> 4. TFmini 为 850nm 红外测距模组，避免正对人眼长时间照射。

---

---

## 1. 部署架构与前置条件

### 1.1 系统拓扑与运行模式

系统由 5 个 Python 模块构成：`main.py`（主控/50Hz 闭环）、`camera_yunet.py`（YuNet 人脸检测）、`tfmini_uart.py`（激光测距后台线程）、`gimbal_can.py`（GL40 电机 SocketCAN 驱动）、`mjpeg_stream.py`（Flask MJPEG 推流）。**全部运行模式均为硬编码，无命令行参数**，标准运行方式即 `python3 main.py`：

| 子系统 | 硬件 | 运行模式（源码锚点） |
| :--- | :--- | :--- |
| 视觉采集 | IMX219（CSI） | Picamera2 视频配置，采集 1640×1232 RGB888，`FrameDurationLimits=(20000,20000)`（50fps），推流/推理缩放至 640×480 |
| 人脸检测 | YuNet ONNX 2023mar | `cv2.FaceDetectorYN`，`score_threshold=0.6`，`nms_threshold=0.3`，`top_k=5000` |
| 激光测距 | 北醒 TFmini Plus | UART `/dev/serial0` @ 115200，daemon 后台线程，9 字节帧 `0x59 0x59`，强度门限 `strength>100` |
| 电机驱动 | CubeMars GL40 ×2 | SocketCAN `can0` @ 1Mbps，速度模式，Yaw=`0x201` / Pitch=`0x202`，float32 小端 + 4 字节补零 |
| 控制闭环 | main.py | 50Hz（`CONTROL_PERIOD=0.02`），P 型速度控制，`YAW_GAIN=PITCH_GAIN=0.003`，死区 ±15px |
| Web 交互 | Flask | `0.0.0.0:5000`，`/` 索引页 + `/video` multipart MJPEG，JPEG 质量 80，约 33fps 节流 |
| 停机 | main.py `finally` | SIGINT 触发优雅停机链（见 [6.1](#61-post-决策树)） |

### 1.2 硬件接线检查清单

通电前逐项确认（☐ 为必检项）：

- [ ] **XT30 24V 动力母线**：GL40 母线接入 24V 动力电，XT30 插头锁紧，极性与底座标识一致。
- [ ] **CAN 总线**：GL40 侧黄色线接底板 `CAN_H`，蓝色线接底板 `CAN_L`，双绞可靠压接。
- [ ] **终端电阻**：总线两端各一只 **120Ω** 终端电阻（共 2 只），总线断开实测 55~65Ω。
- [ ] **共地检查**：24V 电源负极与树莓派 GND 等电位（万用表蜂鸣档确认）。
- [ ] **CSI 摄像头排线**：IMX219 通过 **15-Pin 转 22-Pin 专用柔性排线**接入 Zero 2 W 的 MIPI CSI-2 接口，排线金手指朝向主板、卡扣压紧。
- [ ] **TFmini UART 交叉连接**：TFmini **TX → Pin 10（RXD）**、**RX → Pin 8（TXD）**，5V 接 Pin 2/4、GND 接 Pin 6/9。
- [ ] **MCP2515 中断线**：底板中断线接 **GPIO25（Pin 22）**，与 `interrupt=25` 配置一致。
- [ ] **SPI0 走线**：MCP2515 模块 SPI 引脚插到底，CS 线接到 SPI0 的片选通道。
- [ ] **供电**：树莓派 5V USB 供电满足 Zero 2 W 要求（建议 ≥2.5A），CAN 板由 24V 母线独立供电。
- [ ] **散热与固定**：SoC 贴装散热片，机壳通风，所有线缆做防松固定。

### 1.3 软件与固件版本兼容矩阵

| 组件 | 基线版本要求 | 来源 | 兼容性说明 |
| :--- | :--- | :--- | :--- |
| Raspberry Pi OS | 64-bit（Bookworm，arm64） | Raspberry Pi Imager | `config.txt` 路径为 `/boot/firmware/config.txt` |
| 内核 | 6.1 / 6.6（随镜像更新） | 发行版仓库 | 需含 `mcp251x`、`can_raw` 驱动 |
| Python | 3.11.x | Debian Bookworm apt | systemd service 直接用 `/usr/bin/python3` |
| OpenCV (python3-opencv) | ≥ 4.6 | Debian Bookworm apt | 必须含 `FaceDetectorYN`（objdetect/dnn 模块） |
| python3-picamera2 | Bookworm 仓库版本 | Debian Bookworm apt | libcamera 新相机栈，配套命令为 `rpicam-hello` 等 |
| python3-numpy | ≥ 1.24 | Debian Bookworm apt | OpenCV 数组依赖 |
| python-can | ≥ 4.0 | pip | SocketCAN 接口 `can.interface.Bus(interface="socketcan")` |
| pyserial | ≥ 3.5 | pip | TFmini `/dev/serial0` @ 115200 |
| Flask | ≥ 2.2 | pip | 开发服务器，勿直接暴露公网 |
| can-utils | Debian 仓库版本 | Debian Bookworm apt | `cansend` / `candump` / `cangen` / `canbusload` |
| 模型 | `face_detection_yunet_2023mar.onnx` | OpenCV Zoo | YuNet 2023mar，实测大小约 232.6 KB |
| 内存 | Zero 2 W 板载 512MB | 硬件 | 进程内存上限 350MB（见 [7.2](#72-生产加固项)） |

### 1.4 部署流程总览 (Mermaid)

```mermaid
flowchart TD
    A(["部署准备"]) --> B["硬件接线检查<br/>XT30 / CAN / CSI / UART"]
    B --> C["烧录 Raspberry Pi OS<br/>64-bit Bookworm"]
    C --> D["首启配置<br/>密码 / 源 / 时区 / 静态IP"]
    D --> E["config.txt 总线配置<br/>SPI / UART / Camera"]
    E --> F{"dmesg 与设备节点验证"}
    F -- "未通过" --> E
    F -- "通过" --> G["SocketCAN 初始化<br/>can0 @ 1Mbps"]
    G --> H["apt + pip 依赖安装"]
    H --> I["ONNX 模型部署<br/>MD5 / 大小校验"]
    I --> J["源码补丁 BUG-01~04<br/>静态自测"]
    J --> K["全链路回归<br/>启动 → 检出 → 跟踪 → 优雅停机"]
    K --> L["systemd 托管<br/>gimbal-tracker.service"]
    L --> M{"回归通过?"}
    M -- "否" --> N["进入第 9 章排障手册"]
    M -- "是" --> O(["交付运行"])
    N --> R["修复后重新回归"]
    R --> K
```

---

## 2. 系统镜像烧录与初始化（SOP）

### 2.1 Raspberry Pi Imager 烧录步骤

- **SOP-02-01**：PC 端安装 Raspberry Pi Imager（官方最新版），插入 microSD 卡（≥16GB，Class10/A1 以上，推荐工业卡）。
- **SOP-02-02**：Device 选择 **Raspberry Pi Zero 2 W**。
- **SOP-02-03**：OS 选择 **Raspberry Pi OS（64-bit）**（Bookworm 基底）；现场无人值守场景推荐 **Raspberry Pi OS Lite（64-bit）** 以压缩攻击面。
- **SOP-02-04**：Storage 选择目标 SD 卡，确认盘符无误后执行 **WRITE**（会全量擦除）。
- **SOP-02-05**：写入完成后安全弹出，插入 Zero 2 W，接好 USB 5V 与以太网，首次上电。
- **SOP-02-06**：新版镜像首启自动扩展根文件系统（见 [2.4](#24-磁盘扩容与镜像备份策略)）；通过路由器后台或 `arp -a` 查询设备 IP 后 SSH 登录。

### 2.2 Headless 免显环境配置

**方法 A：bootfs 空 `ssh` 文件（官方标准做法）**。将烧录后的 SD 卡插入 PC，在唯一可见的 FAT bootfs 分区（Bookworm 中挂载为 `/boot/firmware`）根目录放置一个**空文件** `ssh`（`touch ssh`），首启后即启用 SSH。

**方法 B：Imager 定制化预设（custom.toml）**。Imager 的 Customisation 面板可一次性写入主机名、用户名/密码、时区、Wi-Fi 与 SSH 开关；部分版本支持将该套定制保存为 `custom.toml` 预设文件，便于同一批次设备批量烧录复用（具体字段以所用 Imager 版本对话框为准）。

**方法 C：手工预置账户（无 Imager 场景）**。在 bootfs 根目录创建 `userconf.txt`（Bookworm 仍支持，密码哈希用 `openssl passwd -6` 生成）：`echo 'pi:$6$<哈希值>' > userconf.txt`。

> 注：Bookworm 起，bootfs 放置 `wpa_supplicant.conf` 配 Wi-Fi 的旧方式已不被支持，请改用 Imager 定制化面板或首启后 `raspi-config` 配置网络。

### 2.3 首次启动网络与安全配置

```bash
# 1) 修改默认密码（默认用户 pi，必须修改）
passwd

# 2) apt 换用国内镜像（中科大源，路径已实测可用）
sudo sed -i 's|http://raspbian.raspberrypi.org/raspbian/|https://mirrors.ustc.edu.cn/raspbian/raspbian/|g' /etc/apt/sources.list
sudo sed -i 's|http://archive.raspberrypi.org/debian/|https://mirrors.ustc.edu.cn/raspberrypi/debian/|g' /etc/apt/sources.list.d/raspi.list
sudo apt update && sudo apt upgrade -y

# 3) 时区与语言（中文路径依赖 UTF-8 locale）
sudo timedatectl set-timezone Asia/Shanghai
sudo raspi-config        # Localisation Options -> Locale -> en_US.UTF-8 或 zh_CN.UTF-8
timedatectl status       # 验收: Time zone: Asia/Shanghai (CST, +0800)

# 4) pip 国内源
pip3 config set global.index-url https://mirrors.ustc.edu.cn/pypi/simple
```

**静态 IP（Bookworm 默认 NetworkManager，nmcli 方式）**：

```bash
nmcli con show
sudo nmcli con mod "Wired connection 1" ipv4.method manual ipv4.addresses 192.168.1.100/24,192.168.1.1 ipv4.dns 223.5.5.5,119.29.29.29
sudo nmcli con up "Wired connection 1"
ip addr show eth0        # 验收: inet 192.168.1.100/24
```

**静态 IP（dhcpcd 传统方式，若网络仍由 dhcpcd 管理）**：

```bash
sudo apt install -y dhcpcd
sudo bash -c 'cat >> /etc/dhcpcd.conf <<EOF
interface eth0
static ip_address=192.168.1.100/24
static routers=192.168.1.1
static domain_name_servers=223.5.5.5
EOF'
sudo systemctl enable dhcpcd && sudo systemctl restart dhcpcd
```

### 2.4 磁盘扩容与配置备份策略

- **磁盘扩容**：新版镜像首启自动扩展。若未生效：`sudo raspi-config` → Advanced Options → Expand Filesystem，随后 `df -h /` 验收根分区应接近 SD 卡容量（如 32GB 卡 ≈ 29G）。
- **配置基线备份（推荐）**：关键配置随 SOP 打包归档，脚本见 [10.3](#103-备份与一键恢复)。
- **整卡镜像备份（SD Card Copier 思路）**：桌面版使用「附件 → SD Card Copier」整卡克隆；无桌面环境时离线 `sudo dd if=/dev/mmcblk0 of=gimbal-os-backup-$(date +%F).img bs=4M status=progress`。
- **写磨损控制**：journald 设持久化上限（见 [7.4](#74-journald-持久化与日志检索)），避免日志涨满 SD 卡（失效模式见 F-04）。

---

## 3. 底层总线驱动配置与验证

### 3.1 config.txt 设备树配置全量块

Bookworm 路径为 **`/boot/firmware/config.txt`**（早期镜像为 `/boot/config.txt`）。编辑：`sudo nano /boot/firmware/config.txt`，在文件末尾追加：

```ini
# =================================================================
# 跟踪云台底板硬件接口驱动配置
# =================================================================

# 1. 启用硬件 SPI 控制器
dtparam=spi=on

# 2. 加载 MCP2515 CAN 驱动叠加项:
# - oscillator=8000000: 板载 SMD3225 晶振实际频率为 8.000MHz
# - interrupt=25: 底板硬件中断线接入树莓派 GPIO25 (Pin 22)
# - spimaxfrequency=10000000: SPI 最大时钟频率设定为 10MHz
dtoverlay=mcp2515-can0,oscillator=8000000,interrupt=25,spimaxfrequency=10000000
dtoverlay=spi-bcm2835

# 3. 启用主硬件串口并禁用板载蓝牙占用
enable_uart=1
dtoverlay=disable-bt

# 4. 摄像头自动探测启用
camera_auto_detect=1
```

配置语义：`enable_uart=1` + `dtoverlay=disable-bt` 使 **PL011 硬件串口固定映射到 `/dev/serial0`**（不再受 mini-UART 波特率随 CPU 变频漂移影响），同时释放蓝牙占用的 `/dev/ttyAMA0`。保存后 `sudo reboot`。

### 3.2 设备树加载验证

- **验收判据 A（CAN 驱动）**：`dmesg | grep -i mcp2515` 应出现初始化成功信息（设备号以实际为准）：
  ```bash
  # 预期输出（示例）: [    4.126401] mcp251x spi0.0 can0: MCP2515 successfully initialized.
  ```
- **验收判据 B（串口映射）**：`ls -l /dev/serial0` 必须是指向 `ttyAMA0` 的软链接（PL011 在位）：
  ```bash
  # 预期输出（示例）: lrwxrwxrwx 1 root root 7 Oct  4 09:00 /dev/serial0 -> ttyAMA0
  ```
- **验收判据 C（摄像头探测）**：`vcgencmd get_camera` 预期 `supported=1 detected=1`；`rpicam-hello --list-cameras` 应列出 IMX219（Bookworm 提供；旧镜像为 `libcamera-hello`）。
- **验收判据 D（网络接口生成）**：`ls /sys/class/net/` 应包含 `can0`。随后禁用串口控制台登录并加入串口组（防止串口 debug 打印干扰 TFmini）：
  ```bash
  sudo systemctl stop serial-getty@ttyAMA0.service
  sudo systemctl disable serial-getty@ttyAMA0.service
  sudo usermod -a -G dialout $USER
  sudo reboot
  ```

### 3.3 串口与蓝牙设备树冲突排查

`dmesg` 无 MCP2515 初始化信息、或无 `can0` 接口时，按序排查：

1. **CS 片选冲突**：`grep -E "dtoverlay|dtparam" /boot/firmware/config.txt`，确认没有其它 overlay（如 SPI 从设备、`spi0-2cs` 等）占用 SPI0 CS0/GPIO8 或中断 GPIO25，有则删除冲突行后 reboot。
2. **GPIO25 复用**：`raspi-gpio get 25` 查看 GPIO25 功能分配，若被其它外设复用则调整底板跳线或 overlay 参数。
3. **SPI 主控未启用**：确认 `dtparam=spi=on` 存在；`ls /dev/spidev*` 应能看到 `spidev0.0`。
4. **晶振参数不匹配**：`oscillator=8000000` 必须与底板晶振实际频率一致；误配将导致位定时错误、总线错误计数飙升。
5. **中断线断链**：万用表测量 GPIO25（Pin 22）到底板 INT 的通断。

### 3.4 SocketCAN 初始化与开机自启配置

MCP2515 驱动加载后生成网络接口 `can0`。手动激活：

```bash
sudo ip link set can0 type can bitrate 1000000   # 波特率 1Mbps
sudo ip link set dev can0 txqueuelen 1000        # 发送队列长度（等价 sudo ifconfig can0 txqueuelen 1000）
sudo ip link set can0 up                         # 拉起接口
```

开机自启（ifupdown 方式；若未安装先 `sudo apt install -y ifupdown`）：编辑 `/etc/network/interfaces.d/can0`：

```ini
auto can0
iface can0 can static
    bitrate 1000000
    up /sbin/ip link set $IFACE txqueuelen 1000
```

双通道保险：systemd 单元中另设 `ExecStartPre=/sbin/ip link set can0 up`（见第 7 章），确保网络服务异常时服务启动前 can0 必被拉起。

### 3.5 can0 链路状态参数逐字段解读

```bash
ip -details -statistics link show can0
```

典型输出（数值以现场实际为准）：

```
3: can0: <NOARP,UP,LOWER_UP,ECHO> mtu 16 qdisc pfifo_fast state UNKNOWN mode DEFAULT group default qlen 1000
    link/can  promiscuity 0 minmtu 0 maxmtu 16
    can <TRIPLE-SAMPLING> state ERROR-ACTIVE restart-ms 100
          bitrate 1000000 sample-point 0.875
          tq 62.500 prop-seg 34 phase-seg1 35 phase-seg2 10 sjw 1
          mcp251x: tseg1 2..16 tseg2 2..8 sjw 1..4 brp 1..64
          clock 8000000
          re-stats bus-error arb-lost bus-off 0 0 0
          error-warning 0
          error-passive 0
          bus-off 0
    RX: bytes  packets  dropped overrun mcast
    1726      180      0       0       0
    TX: bytes  packets  errors  dropped carrier collsns
    584       75       0       0       0       0
```

| 字段 | 含义与现场判读 |
| :--- | :--- |
| `state UNKNOWN` + `UP,LOWER_UP` | 接口已使能并工作（CAN 无载波检测概念，显示 UNKNOWN 属正常） |
| `<TRIPLE-SAMPLING>` | MCP2515 三重采样，抗总线毛刺 |
| `state ERROR-ACTIVE` | 错误状态机当前态：正常（其它值见 [3.6](#36-can-总线故障诊断与错误状态机)） |
| `bitrate 1000000` | 位速率，**必须与 GL40 电机一致（1Mbps）** |
| `sample-point 0.875` / `tq` / `brp` | 位定时参数，由 `bitrate` + `clock` 推导 |
| `clock 8000000` | 驱动使用的晶振频率，验证 `oscillator=8000000` 是否生效 |
| `restart-ms 100` | BUS-OFF 后 100ms 自动尝试恢复 |
| `re-stats bus-error / arb-lost / bus-off` | 总线错误帧、仲裁丢失、总线关闭累计次数 |
| `error-warning / error-passive / bus-off` | 各错误阈值越限累计次数 |
| `RX/TX packets` | 收发报文计数（应随控制循环持续增长，约 50Hz×2 报文） |
| `RX/TX errors / dropped` | 收发错误/丢弃计数；`dropped` 增长表示队列或缓冲区拥塞 |
| `qlen 1000` | 发送队列长度，验证 txqueuelen 配置已生效 |

### 3.6 CAN 总线故障状态机与错误计数器诊断

```mermaid
stateDiagram-v2
    [*] --> ERROR_ACTIVE: 上电初始化
    ERROR_ACTIVE --> ERROR_WARNING: TEC 或 REC ≥ 96
    ERROR_WARNING --> ERROR_PASSIVE: TEC 或 REC ≥ 128
    ERROR_PASSIVE --> ERROR_ACTIVE: 计数器回落
    ERROR_PASSIVE --> BUS_OFF: TEC ≥ 256
    BUS_OFF --> ERROR_ACTIVE: 128×11 隐性位后 restart-ms 超时自动恢复
```

- **TEC/REC 语义**：发送节点检测到错误帧时 TEC +8，接收节点 REC +1；TEC ≥ 128 进入 ERROR-PASSIVE（发送须等待间歇），REC ≥ 128 仅限制应答。
- **位速率不匹配的典型现象**：GL40 为 1Mbps 而 can0 配成其它速率时，双方采样点错位 → 错误帧风暴 → 无人 ACK（发送节点收不到应答位将持续重发）→ TEC 迅速累积至 256 → **BUS-OFF**。此时 `candump can0` 完全静默，`ip -details link show can0` 显示 `state BUS-OFF` 且 `bus-off` 计数持续增长。处置：核对两侧位速率后重配 `can0`。
- **总线物理断线**：BUS-OFF 与总线错误计数同步增长；逐段测量 CAN_H/CAN_L 通断与 120Ω×2 终端电阻。
- **总线负载观察**：`canbusload can0` 实时显示总线占用率；静默期异常 >0% 说明存在异常见错误帧。

---

## 4. 运行环境搭建与模型部署

### 4.1 系统底层依赖安装

```bash
# 1) 更新 apt 软件源并安装基础构建依赖
sudo apt update
sudo apt install -y python3-pip python3-opencv python3-picamera2 python3-numpy can-utils git

# 2) 安装 Python 总线通信与 Web 推流相关库
#    Bookworm 为 PEP 668 外部管理环境, 系统级安装必须加 --break-system-packages
pip3 install python-can pyserial flask --break-system-packages

# 3) 安装后立即验证关键能力
python3 -c "import cv2; print('OpenCV', cv2.__version__)"
python3 -c "from cv2 import FaceDetectorYN; print('YuNet detector OK')"
python3 -c "import can, serial, flask; print('can/serial/flask OK')"
```

### 4.2 Python 虚拟环境与依赖管理

PoC 阶段推荐系统级方案（便于 systemd 直接用 `/usr/bin/python3`）；需要多版本共存时使用 venv：

```bash
python3 -m venv --system-site-packages ~/gimbal-venv
source ~/gimbal-venv/bin/activate
pip install --upgrade pip
# venv 内无需 --break-system-packages
pip install python-can pyserial flask
python -c "import cv2, can, serial, flask; print('venv OK, OpenCV', cv2.__version__)"
deactivate    # 退出
```

### 4.3 YuNet ONNX 模型下载与完整性校验

源码 `camera_yunet.py` 将模型硬编码为 `/home/jr/models/face_detection_yunet_2023mar.onnx`（YuNet 2023mar，OpenCV Zoo 分发）。部署并记录校验和：

```bash
# 创建硬编码目录并下载
sudo mkdir -p /home/jr/models
cd /home/jr/models
sudo wget https://github.com/opencv/opencv_zoo/raw/main/models/face_detection_yunet/face_detection_yunet_2023mar.onnx
sudo chmod 644 face_detection_yunet_2023mar.onnx        # 赋予全用户可读权限

# 完整性校验: 记录 MD5 作为黄金指纹, 与分发方(opencv_zoo 仓库/官方 model card)公布值比对
md5sum face_detection_yunet_2023mar.onnx
ls -l face_detection_yunet_2023mar.onnx                 # 辅助校验: 实测约 232.6 KB (2026-10 实测 232589 字节)
```

> 完整性判定规则：① `md5sum` 输出与黄金指纹一致；② 文件大小在 230KB 量级；③ `python3 -c "from cv2 import FaceDetectorYN; FaceDetectorYN.create('/home/jr/models/face_detection_yunet_2023mar.onnx','',(640,480)); print('model load OK')"` 可正常加载。任一项不符即判定模型损坏，重新下载。

### 4.4 硬编码模型路径软链接兼容方案

若部署用户不是 `jr`（例如按第 7 章以 `pi` 用户运行），二选一：

- **方案 A（推荐）**：由 `pi` 目录软链进入硬编码路径：
  ```bash
  sudo mkdir -p /home/pi/models
  sudo wget -P /home/pi/models https://github.com/opencv/opencv_zoo/raw/main/models/face_detection_yunet/face_detection_yunet_2023mar.onnx
  sudo mkdir -p /home/jr && sudo ln -s /home/pi/models /home/jr/models
  ls -l /home/jr/models/face_detection_yunet_2023mar.onnx   # 验收: 链接可达
  ```
- **方案 B（直接落盘）**：`sudo mkdir -p /home/jr/models` 后下载并 `chmod 644`，保持源码不改；参数化多机部署时需同步维护该目录。

---

## 5. 源码缺陷审计与加固补丁 (Bug Audit)

在对全部 5 个 Python 源代码逐行静态审查中，排查出 **2 项首帧必崩的致命缺陷**与 **2 项稳定性缺陷**。所有补丁均以小侵入方式提供，打完补丁后必须执行 [5.4](#54-补丁验证步骤) 与 [5.5](#55-全链路回归验证清单)。

### 5.1 缺陷全景审计表 (CVSS 评级)

| 缺陷编号 | 严重度 (CVSS) | 触发位置 | 缺陷触发根因 | 崩溃现象与影响评估 |
| :---: | :---: | :--- | :--- | :--- |
| **BUG-01** | <font color=red>**CRITICAL (9.1)**</font> | `main.py:123` | `camera.detect_largest_face(frame)` 方法未定义！`YuNetCamera` 类唯一定义的方法为 `detect_faces`。 | **首帧抛出 `AttributeError` 崩溃退出**，云台完全无法启动闭环控制。 |
| **BUG-02** | <font color=red>**CRITICAL (8.8)**</font> | `main.py:75` | `draw_overlay` 试图访问 `face['count']`，但 `detect_faces` 返回的目标字典仅含 `x,y,w,h,cx,cy,area`。 | **首帧检出人脸立即抛出 `KeyError: 'count'` 崩溃**。 |
| **BUG-03** | <font color=orange>**MEDIUM (5.3)**</font> | `camera_yunet.py:50` | `frame = cv2.cvtColor(frame, cv2.COLOR_RGB2BGR)` 被意外注释。Picamera2 输出 RGB，而 OpenCV/YuNet 需 BGR。 | **检测置信度严重劣化并产生漏检**；Web 推流十字准星红蓝颜色互换。 |
| **BUG-04** | <font color=blue>**LOW (3.1)**</font> | `gimbal_can.py` | CAN 总线发送缺乏 `try...except can.CanError` 保护与总线脱机自动重连机制。 | 总线瞬态断连或从机脱机时主循环线程挂起阻断（`send(timeout=0.05)` 抛异常无人捕获）。 |

### 5.2 补丁一：camera_yunet.py 修复补丁

入口前先备份：`cp camera_yunet.py camera_yunet.py.bak`。打开 `2、软件代码/project/camera_yunet.py`，更新 `read()` 并追加 `detect_largest_face()` 方法：

```python
    def read(self):
        frame = self.picam2.capture_array()
        frame = cv2.resize(frame, self.stream_size)

        # [修复 BUG-03]: 恢复色彩空间转换，Picamera2 RGB 转换为 OpenCV 标准 BGR
        frame = cv2.cvtColor(frame, cv2.COLOR_RGB2BGR)

        return frame

    def detect_largest_face(self, frame):
        """
        [修复 BUG-01 & BUG-02]: 补充与 main.py 匹配的接口，并注入 count 统计字段
        """
        results, selected_face = self.detect_faces(frame)
        if selected_face is not None:
            # 注入人脸总数，消除 main.py draw_overlay 抛出的 KeyError: 'count'
            selected_face["count"] = len(results)
        return selected_face
```

### 5.3 补丁二：main.py 异常保护补丁

入口前先备份：`cp main.py main.py.bak`。在 `2、软件代码/project/main.py` 的主循环目标捕获段添加防御性解包逻辑：

```python
        while True:
            frame = camera.read()

            # 防御性调用：优先调用 detect_largest_face，若未打补丁则回退至 detect_faces
            try:
                face = camera.detect_largest_face(frame)
            except AttributeError:
                faces_list, face = camera.detect_faces(frame)
                if face is not None:
                    face["count"] = len(faces_list)

            distance = lidar.get_distance()
```

> **BUG-04 加固建议（可选）**：为 `gimbal_can.py` 的发送路径增加 CAN 异常保护，避免总线脱机时主循环中断：
> ```python
>     def send(self, can_id, data):
>         msg = can.Message(arbitration_id=can_id, data=data, is_extended_id=False)
>         try:
>             self.bus.send(msg, timeout=0.05)   # 总线脱机时抛 CanError 而非挂起
>         except can.CanError as e:
>             print(f"CAN send error: {e}")      # 生产环境建议改 journal 落盘
> ```

### 5.4 补丁静态验证单测步骤

以下静态自测**不触碰硬件**（模块构造均发生在 `main()` 内，导入安全），每条独立判定：

```bash
cd "/home/pi/gimbal/2、软件代码/project"

# V1: 模块可导入（main.py 有 __main__ 守卫，导入不会触发主流程）
python3 -c "import main; print('V1 OK: 模块导入无错误')"

# V2: BUG-01 —— detect_largest_face 接口存在
python3 -c "from camera_yunet import YuNetCamera; assert hasattr(YuNetCamera,'detect_largest_face'); print('V2 OK: BUG-01 接口已补齐')"

# V3: BUG-03 —— 色彩空间转换已恢复
python3 -c "import inspect; from camera_yunet import YuNetCamera; assert 'COLOR_RGB2BGR' in inspect.getsource(YuNetCamera.read); print('V3 OK: BUG-03 RGB2BGR 已恢复')"

# V4: BUG-02 —— count 字段注入逻辑存在
python3 -c "import inspect; from camera_yunet import YuNetCamera; assert 'count' in inspect.getsource(YuNetCamera.detect_largest_face); print('V4 OK: BUG-02 count 字段已注入')"

# V5: BUG-04 —— CAN 发送异常保护已就位（打可选补丁后必须通过）
python3 -c "import inspect; from gimbal_can import GimbalCAN; assert 'CanError' in inspect.getsource(GimbalCAN.send); print('V5 OK: BUG-04 CAN 异常保护已就位')"
```

V1~V4 全部输出 `OK` 方可进入回归；V5 视是否采用 BUG-04 可选补丁而定。

### 5.5 全链路回归验证清单

手动执行 `python3 main.py`，按序核对（任一项失败即回到第 9 章对应条目排障）：

| 步骤 | 操作 | 通过判据 |
| :---: | :--- | :--- |
| R-1 | `python3 main.py` | 终端打印 `Starting speed-mode face tracking...` 与 `http://<raspberrypi_ip>:5000`，无 Traceback |
| R-2 | 浏览器访问 `http://<IP>:5000` | 首页显示 `YuNet Face Tracking + TFmini`，`/video` 出图 |
| R-3 | 摄像头对准人脸 | 画面出现绿色人形框，左上角 `faces=N`（N≥1，多脸场景 N 正确） |
| R-4 | 移动人脸至画面中心 | 中心十字准星由红变绿（目标进入死区） |
| R-5 | 观察 `err_x/err_y` | 数值随目标实时收敛至 \|err\| ≤ 15px 死区内 |
| R-6 | 观察右下测距 | `Distance: N cm` 正常刷新（TFmini 有效距离内） |
| R-7 | 观察云台机械动作 | Yaw/Pitch 朝目标平滑转动，无飞车无异响 |
| R-8 | 遮挡目标 | 目标丢失后电机停转（`gimbal.stop()` 下发 0.0 rad/s），画面显示 `No face` |
| R-9 | `Ctrl+C` | 打印 `Stopping...`，按 `stop→sleep 0.2→disable→close→lidar.stop` 链执行后打印 `Exit.`，电机相线 PWM 释放 |

---

## 6. 开机自检 (POST) 与运行时故障隔离

### 6.1 POST 决策树 (Mermaid)

```mermaid
flowchart TD
    BOOT(["systemd 拉起 python3 main.py"]) --> P1{"模型文件存在?<br/>/home/jr/models/face_detection_yunet_2023mar.onnx"}
    P1 -- "否" --> E1["YuNetCamera 构造抛 FileNotFoundError<br/>进程退出 → systemd Restart 循环"]
    P1 -- "是" --> P2{"CSI 摄像头可用?<br/>Picamera2.start"}
    P2 -- "失败" --> E2["摄像头硬件故障/排线未插牢<br/>进程退出 → systemd Restart"]
    P2 -- "成功" --> P3{"can0 已就绪?<br/>ip link show can0"}
    P3 -- "未就绪" --> E3["GimbalCAN 构造抛 CanError<br/>现状: 直接退出; 加固版: 纯视觉降级"]
    P3 -- "就绪" --> P4{"串口可打开?<br/>/dev/serial0"}
    P4 -- "失败" --> E4["TFmini 未接线/权限不足<br/>后台线程打印 TFmini error<br/>降级: 测距显示 -- cm"]
    P4 -- "成功" --> P5["进入 50Hz 闭环跟踪 + Flask:5000 推流"]
    P5 --> RUN{"RUN_LOOP 运行态监测"}
    RUN -- "CAN 发送超时/错误" --> F1["加固版: 记录异常并复位 can0"]
    RUN -- "目标丢失" --> F2["下发 0.0 rad/s 停转"]
    RUN -- "捕获 SIGINT (Ctrl+C)" --> EXIT["优雅停机: 电机停转 → 失能 → 退出"]
```

POST 关键结论（与源码行为严格对应）：

1. **模型缺失**：`camera_yunet.py:15` 的 `os.path.exists` 检查直接抛 `FileNotFoundError`，属**硬失败**（当前版本无降级路径）。
2. **摄像头不可用**：`Picamera2.start()` 失败属硬失败。
3. **can0 未就绪**：`GimbalCAN.__init__` 中 `can.interface.Bus(...)` 抛 `CanError` 且无人捕获，属硬失败——第 3 章 can0 初始化是 POST 前置必需项。
4. **TFmini 不可用**：串口异常在 `_loop()` 线程内被捕获打印，`self.distance` 保持 `None`，界面显示 `-- cm`，属**可接受降级**。
5. **优雅停机链**（`main.py` finally）：`gimbal.stop()` → `time.sleep(0.2)` → `gimbal.disable()` → `gimbal.close()` → `lidar.stop()`；任一步异常均打印 `Shutdown error: ...` 后继续走完剩余步骤。

### 6.2 运行时守护与分级降级策略

| 守护层 | 机制 | 触发与动作 |
| :--- | :--- | :--- |
| L1 进程守护 | systemd `Restart=always` + `RestartSec=3` | 进程退出/被杀后 3s 自动重启；配合 `StartLimitBurst` 防止风暴重启 |
| L2 心跳守护 | `WatchdogSec` + sdnotify 心跳（[7.3](#73-sdnotify-看门狗心跳实现)） | 主循环阻塞超 30s 未发 `WATCHDOG=1` → 判定僵死 → SIGKILL 后重启 |
| L3 运行时长 | `RuntimeMaxSec=86400` | 每日强制重建进程，规避长跑内存/句柄泄漏 |
| L4 降级运行 | 模块内 try/except | TFmini 断线 → 测距 `-- cm`；CAN 加固后 → 总线瞬断不中断视觉链路 |
| L5 可观测 | journald 持久化（[7.4](#74-journald-持久化与日志检索)） | `journalctl -u gimbal-tracker -p err` 值班巡检入口 |

---

## 7. systemd 生产级服务托管与保活

### 7.1 基线 unit 单元配置文件

为了让跟踪云台上电后无人值守自动拉起并在异常崩溃后自动重启，编写 systemd 单元 `sudo nano /etc/systemd/system/gimbal-tracker.service`：

```ini
[Unit]
Description=Two-Axis Vision & LiDAR Tracking Gimbal Service
After=network.target network-online.target
Wants=network-online.target

[Service]
Type=simple
User=pi
WorkingDirectory=/home/pi/gimbal/2、软件代码/project
ExecStartPre=/sbin/ip link set can0 up
ExecStart=/usr/bin/python3 main.py
Restart=always
RestartSec=3
KillMode=process
TimeoutStopSec=5

[Install]
WantedBy=multi-user.target
```

基线说明：`KillMode=process` 表示 `systemctl stop` 时只向主进程发信号（Flask/TFmini 均为进程内线程，随主进程一并退出）；`TimeoutStopSec=5` 给出优雅停机链 5s 预算，超时 SIGKILL 兜底；`Restart=always` 对任何退出（含 0 码退出）都重启，若希望仅异常退出重启可改为 `Restart=on-failure`（服务态无终端，推荐保留 `always`）。激活：

```bash
sudo systemctl daemon-reload
sudo systemctl enable gimbal-tracker.service
sudo systemctl start gimbal-tracker.service
```

### 7.2 生产加固配置 (资源限制与策略)

在基线之上追加以下加固指令（叠加为完整加固版单元）：

```ini
[Service]
Type=notify                    # 配合 sdnotify 就绪通知与看门狗 (需替换 Type=simple)
# —— 看门狗与运行时长 ——
WatchdogSec=30                 # 30s 未收到 WATCHDOG=1 判定僵死, SIGKILL 后按 Restart 拉起
RuntimeMaxSec=86400            # 单次运行最长 24h, 到点重建进程 (内存卫生)
# —— 资源限制 ——
MemoryMax=350M                 # 512MB 物理内存下为系统预留余量, 超限触发 OOM 策略
CPUQuota=80%                   # 限制 CPU 占用 80%, 防止满负荷抢占系统调度
OOMPolicy=stop                 # 达到 MemoryMax 时停止该 cgroup
# —— 防重启风暴 ——
StartLimitIntervalSec=300
StartLimitBurst=5
# —— 基线保留项 ——
Restart=always
RestartSec=3
KillMode=process
TimeoutStopSec=5
```

改动后 `sudo systemctl daemon-reload && sudo systemctl restart gimbal-tracker`。

### 7.3 sdnotify 看门狗心跳实现代码

`WatchdogSec` 生效两要素：单元 `Type=notify`；Python 进程初始化完成后向 `$NOTIFY_SOCKET` 发送 `READY=1`，并以 `< WatchdogSec/2` 的间隔持续发送 `WATCHDOG=1`。新增 `gimbal_watchdog.py`（零三方依赖，直接实现 sd_notify(3) 协议）：

```python
# gimbal_watchdog.py —— systemd sdnotify 就绪通知与看门狗心跳
import os
import socket
import threading

class SdNotifier:
    """最小依赖实现 sd_notify(3): READY=1 就绪通知 + WATCHDOG=1 心跳"""

    def __init__(self):
        self._sock = None
        addr = os.environ.get("NOTIFY_SOCKET")
        if addr:
            if addr.startswith("@"):          # Linux 抽象命名空间地址
                addr = "\0" + addr[1:]
            self._sock = socket.socket(socket.AF_UNIX, socket.SOCK_DGRAM)
            self._sock.connect(addr)

    def notify(self, state):
        if self._sock is not None:
            self._sock.sendall(state.encode())

    def ready(self):
        self.notify("READY=1\nSTATUS=跟踪主循环运行中\n")

    def watchdog(self):
        self.notify("WATCHDOG=1\n")

def start_heartbeat(period=5.0):
    """period 必须 < WatchdogSec/2 (单元配 30s, 此处取 5s)"""
    sd = SdNotifier()
    sd.ready()
    stop = threading.Event()

    def _beat():
        while not stop.wait(period):
            sd.watchdog()

    threading.Thread(target=_beat, daemon=True).start()
    return stop
```

在 `main.py` 集成（`gimbal.enable()` 序列之后启动、`finally` 首行收尾）：`from gimbal_watchdog import start_heartbeat; watchdog_stop = start_heartbeat(5.0)`，`finally` 块首行加 `watchdog_stop.set()`。未集成心跳时**不要**将 `Type` 改为 `notify`，否则 systemd 将在 30s 后判定启动失败并反复重启。

### 7.4 journald 日志持久化与检索命令

编辑 `/etc/systemd/journald.conf`：

```ini
[Journal]
Storage=persistent
SystemMaxUse=256M
SystemMaxFileSec=1month
RuntimeMaxUse=64M
```

```bash
sudo systemctl restart systemd-journald
sudo usermod -aG systemd-journal pi     # 允许 pi 免密读日志
journalctl --disk-usage                 # 日志磁盘占用
```

日志查询命令集：

```bash
journalctl -u gimbal-tracker -f --no-pager                    # 实时跟踪
journalctl -u gimbal-tracker --since "30 min ago" -p warning  # 近30分钟告警以上
journalctl -u gimbal-tracker -b -o cat -n 200                 # 本次启动最近200行(仅正文)
journalctl -u gimbal-tracker --since today -o short-precise   # 今日带毫秒时间戳
sudo journalctl --vacuum-size=100M                            # 手动清理至100M
```

### 7.5 服务启停与状态诊断常用命令套件

```bash
sudo systemctl daemon-reload                                  # 改动 unit 后重载
sudo systemctl enable --now gimbal-tracker.service            # 启用并启动
systemctl is-active gimbal-tracker                            # active/inactive/failed
sudo systemctl status gimbal-tracker --no-pager -l            # 详情(含近期日志与退出码)
sudo systemctl restart gimbal-tracker                         # 重启
sudo systemctl stop gimbal-tracker                            # 触发优雅停机链(5s预算)
sudo systemctl show gimbal-tracker -p WatchdogTimestamp -p MemoryCurrent
sudo systemctl kill --signal=SIGINT gimbal-tracker            # 仅发 SIGINT 不杀 cgroup
sudo systemctl reset-failed gimbal-tracker                    # 重启风暴用尽后复位
# 值班巡检三连:
systemctl is-active gimbal-tracker && journalctl -u gimbal-tracker --since "1 hour ago" -p err -o cat && vcgencmd measure_temp
```

---

## 8. FMECA 运维失效分析与应急预案

严重度等级（MIL-STD-882F）：**I 类灾难性**（人员死亡/系统损毁）、**II 类严重**（人员重伤/任务失败）、**III 类轻度**（任务降级）、**IV 类轻微**。

| 编号 | 失效模式 | 诱因 | 对系统影响 | 严重度 | 现场检测手段 | 恢复动作 | 预防措施 |
| :---: | :--- | :--- | :--- | :---: | :--- | :--- | :--- |
| F-01 | CAN 总线脱线/断线 | 接插件松脱、断线、共地缺失 | 跟踪闭环失效，电机失能 | III | `candump can0` 静默；`ip -d link show can0` 错误计数增长 | 断电重接；必要时 `ip link set can0 down` 后重新 `up` 复位 | 线缆应力释放固定；插头点漆防松 |
| F-02 | CAN 位速率不匹配 | 两侧 bitrate 配置不一致 | 无 ACK → BUS-OFF，完全失联 | II | `candump` 无数据；`state BUS-OFF`；bus-off 计数增长 | 统一两侧为 1Mbps 后重启服务 | 变更受控（OP-CI-02）；上线前注入测试 |
| F-03 | 摄像头排线松脱 | 振动导致 CSI 排线移位 | 视觉中断，进程崩溃重启循环 | II | `vcgencmd get_camera` detected=0；日志 Picamera2 异常 | 断电重插排线后重启服务 | 排线卡扣压紧并点胶；机箱减振 |
| F-04 | SD 卡写满/损坏 | 日志涨满、掉电写损 | 系统只读或无法启动 | II | `df -h /` 使用率 >90%；`dmesg` 报 I/O error | 更换工业级 SD 卡并从黄金镜像恢复 | journald 上限 + 季度镜像巡检 |
| F-05 | 电源跌落/欠压 | 24V 电池低压、USB 供电不足 | 进程异常退出、看门狗重启 | II | `vcgencmd get_throttled` 非 0x0；日志重启痕迹 | 更换电源/电池后重新上线 | 电源冗余与低压告警 |
| F-06 | 电机/驱动过温 | 机械卡滞、动平衡不良、长时间堵转 | 电机退磁风险、云台停机 | II | `vcgencmd measure_temp`；电机外壳烫手感 | 立即断电降温，检查轴系后限功率复测 | 装配动平衡；死区内低增益 |
| F-07 | 模型文件丢失/损坏 | 误删、拷贝不完整、盘损坏 | POST 硬失败，FileNotFoundError | II | [5.4](#54-补丁验证步骤) V 系列 + `md5sum` 比对 | 从备份/官方源重下模型并校验 | 模型纳入 OP-CI-04 随备份包归档 |
| F-08 | 5000 端口冲突 | 其它进程占用 | Web 推流不可用 | III | `sudo netstat -tlpn \| grep 5000`；日志 `Address already in use` | 停掉占用进程或调整实例 | 部署前端口基线核查 |
| F-09 | 串口占用/TFmini 断线 | serial-getty 未禁、探头脱焊、10cm 盲区 | 测距降级为 `-- cm` | III | `lsof /dev/ttyAMA0`；日志 `TFmini error` | 释放串口/重接探头 | 部署 SOP 强制 `disable serial-getty@ttyAMA0` |
| F-10 | 设备树冲突/晶振误配 | 其它 overlay 占 SPI0/GPIO25 | can0 不生成，POST 硬失败 | II | `dmesg \| grep -i mcp2515` 无输出；无 `can0` 接口 | 清理冲突 overlay 后 reboot | [3.3](#33-设备树冲突排查) 检查单受控 |
| F-11 | 进程 OOM/无限重启 | 内存泄漏、加固限制过紧、启动风暴 | 服务不可用 | III | `systemctl status` 退出码非零；`dmesg \| grep -i oom` | 分析泄漏点；必要时评估后调 `MemoryMax` | L2/L3 守护 + `StartLimitBurst` 限流 |

---

## 9. 现场排障手册

> 使用约定：P-01~P-11 每条为完整 SOP（现象 → 根因假设树 → 诊断命令链 → 修复动作 → 预防措施）；命令均在 Raspberry Pi OS Bookworm 真实可执行；表中 `<IP>` 为树莓派实际地址。

| 编号 | 故障现象 | 根因假设树 | 诊断命令链 | 修复动作 | 预防措施 |
| :---: | :--- | :--- | :--- | :--- | :--- |
| **P-01**<br/>模型缺失 | 启动即报 `FileNotFoundError: '/home/jr/models/face_detection_yunet_2023mar.onnx'`，进程退出并进入 systemd Restart 循环 | 模型未下载 → 部署用户非 `jr` 且未做路径兼容 → `pi` 无读权限 → 文件拷贝不完整（md5/大小不符） | `ls -l /home/jr/models/face_detection_yunet_2023mar.onnx`；`sudo -u pi test -r <模型路径> && echo readable`；`md5sum <模型路径>`；`journalctl -u gimbal-tracker -b -o cat -n 30` | 按 [4.3](#43-onnx-模型部署与完整性校验) 重新下载并 `chmod 644`；路径不匹配按 [4.4](#44-模型路径兼容方案) 软链 | 模型纳入 OP-CI-04 随备份包归档；恢复后执行 V 系列自测 |
| **P-02**<br/>can0 不存在 | 日志出现 `OSError: [Errno 19] No such device (can0)` 或 `can.CanError`，进程退出重启循环 | config.txt 未写/未生效 → MCP2515 overlay 加载失败（CS/中断冲突）→ 晶振参数误配 → MCP2515 硬件损坏 | `dmesg \| grep -i mcp2515`；`grep -E "spi\|mcp2515" /boot/firmware/config.txt`；`ls /sys/class/net/`；`ls /dev/spidev*`；`ip link show can0` | 按 [3.3](#33-设备树冲突排查) 清理冲突 overlay，确认 `interrupt=25` 与底板一致，`sudo reboot` 后重跑验收判据 A/D；手动兜底 `sudo ip link set can0 type can bitrate 1000000 && sudo ip link set can0 up` | config.txt 作为 OP-CI-01 纳入基线与变更评审；镜像恢复后重跑第 3 章验收判据 |
| **P-03**<br/>电机震荡飞车 | 发送使能帧后电机猛烈震荡、啸叫或飞转，可能伴随过热 | 极性反接/方向常数不匹配 → 增益过大 → 死区过小 → 机械轴系卡滞/质心偏离 → GL40 侧参数被改动 | **先断电**；`cangen can0 -v &`（观察总线收发）；`cansend can0 201#CDCC4C3D00000000`（0.05 rad/s 极低速，观察转向与平稳性） | 确认 `main.py` 中 `YAW_DIRECTION = -1`；若装配时电机反装，需将极性方向改为 `+1`（Pitch 对应 `PITCH_DIRECTION`）；机械问题重新做动平衡；必要时下调 `YAW_GAIN` | 无机械限位与动平衡前禁止全环路运行；低速往返测试纳入出厂 SOP |
| **P-04**<br/>测距无输出 | Web 画面右下角恒定 `Distance: -- cm`，日志可能出现 `TFmini error: ...` | 串口未交叉（TX/RX 接反）→ 串口被 serial-getty 占用/权限不足 → 探头进入 10cm 盲区或无有效回波 → 5V 供电不足 | `ls -l /dev/serial0`；`groups pi \| grep dialout`；`sudo lsof /dev/ttyAMA0`；`python3 -c "import serial; s=serial.Serial('/dev/serial0',115200,timeout=1); print(s.read(20).hex())"`；`dmesg \| grep -i ttyAMA0` | TX/RX 交叉重接；`sudo systemctl disable serial-getty@ttyAMA0`；`sudo usermod -aG dialout pi` 后重新登录；裸传数据为 `5959...` 持续说明模组正常，检查目标反射率与盲区 | 850nm 红外可用手机摄像头观察微弱红光辅助确认探头工作；接线纳入 [1.2](#12-硬件接线检查清单) |
| **P-05**<br/>Web 无法访问 | 浏览器访问 `http://<IP>:5000` 无响应或拒绝连接 | Flask 线程未起到 → 端口被其它进程占用 → 防火墙未放行 → 网络/VLAN 不通 → 多客户端拖垮 CPU | `sudo netstat -tlpn \| grep 5000`；`sudo ss -tlpn \| grep 5000`；`sudo ufw status verbose`；`curl -I http://<IP>:5000/`；`journalctl -u gimbal-tracker -f \| grep -iE "5000\|running on"` | `sudo ufw allow 5000/tcp`（见 [10.2](#102-防火墙与串口用户组)）；停掉端口占用进程；确认日志出现 `Running on http://0.0.0.0:5000` | 端口基线纳入部署 SOP；5000 为 Flask 开发服务器，禁止暴露公网（NIST SP 800-123 最小暴露面） |
| **P-06**<br/>电机静态过热 | 使能后静置数分钟，电机外壳烫手（>60℃ 体感阈值） | 机械轴系未达动平衡或安装干涉 → 俯仰轴质心偏离旋转轴 → 轴承阻尼不均/卡滞 → 零位死区持续出力 → 环境温度过高 | `vcgencmd measure_temp`；断电后手动盘动云台感受阻尼均匀性；检查俯仰轴质心 | 重新配平；确认无卡滞；缩短静态使能时长；若为 GL40 固件参数问题回滚基线 | 出厂前做 30 分钟静态温升测试（阈值受控），纳入 F-06 预防项 |
| **P-07**<br/>推流卡顿掉帧 | Web 画面明显掉帧、花屏或延迟增大 | 多客户端并发（每客户端独立 `imencode` 线程）→ CPU 饱和 → Wi-Fi 信号弱/丢包 → SD 卡 I/O 抖动 → JPEG 质量偏高 | `top -p $(pgrep -f "python3 main.py") -n 1`；`vcgencmd measure_temp`；`vcgencmd get_throttled`；`iw dev wlan0 station dump \| grep -i signal` | 减少并发客户端（建议 ≤2）；优先改用有线以太网；临时下调 `mjpeg_stream.py` 的 `IMWRITE_JPEG_QUALITY`（如 60）；确认无 `CPUQuota` 误配限流（`systemctl show gimbal-tracker -p CPUQuotaPerSecUSec`） | 现场部署优先有线网络；客户端数量纳入值班规范 |
| **P-08**<br/>Ctrl+C 无法退出 | 前台运行 `python3 main.py` 后按 Ctrl+C 无反应，或 systemd 托管时按键无效 | 服务态运行无控制终端（SIGINT 无投递对象）→ 进程在后台/其它 SSH 会话 → 非主线程阻塞拖慢响应 → 终端将 Ctrl+C 解释为剪贴板 | `systemctl stop gimbal-tracker`（服务态标准停机方式）；`pgrep -af "python3 main.py"`；必要时 `sudo systemctl kill --signal=SIGINT gimbal-tracker` | 服务态一律用 `sudo systemctl stop gimbal-tracker`（5s 内走优雅停机链，超时 SIGKILL 兜底）；前台态确认焦点在运行终端；残留进程用 `sudo kill -INT <pid>` | 值班 SOP 明确「停电机先 systemctl stop」；禁止 `kill -9` 主进程（跳过 finally 停机链，电机保持使能） |
| **P-09**<br/>总线静默与 BUS-OFF | `candump can0` 长时间无任何报文，电机无响应，云台静止 | bitrate 不匹配（无 ACK → TEC 累积 BUS-OFF）→ 总线物理断线/终端电阻缺失 → 24V 母线断电（从机整体掉电）→ MCP2515 未从 BUS-OFF 恢复 | `ip -details -statistics link show can0 \| grep -E "state\|bus-off\|errors"`；`candump can0,201:7FFFFFF &`；`cansend can0 201#FFFFFFFFFFFFFFFC`；`canbusload can0` | 状态为 `BUS-OFF` 时 `sudo ip link set can0 down && sudo ip link set can0 type can bitrate 1000000 && sudo ip link set can0 up`（复位错误状态）；核查两侧 1Mbps、120Ω×2、24V 供电后重启服务 | 见 F-01/F-02；每日 `canbusload` 巡检纳入值班表 |
| **P-10**<br/>服务反复重启 | `systemctl status` 显示 `activating (auto-restart)`，`MemoryCurrent` 接近上限或退出码非零 | 依赖资源缺失（can0/模型/摄像头，按 P-01/P-02）→ 内存超 `MemoryMax=350M` 被 OOM 策略停止 → 未捕获异常循环 + `Restart=always` → `StartLimitBurst=5` 用尽进入 failed | `systemctl status gimbal-tracker --no-pager -l`；`journalctl -u gimbal-tracker -b --since "-1 hour" -o cat`；`dmesg \| grep -iE "killed process\|oom"`；`systemctl show gimbal-tracker -p MemoryCurrent -p NRestarts` | 按日志根因修复后 `sudo systemctl reset-failed gimbal-tracker && sudo systemctl start gimbal-tracker`；确认内存策略未过紧（350M 为该负载经验值） | 变更必须走 [5.4](#54-补丁验证步骤) 静态自测；资源限额纳入 OP-CI-05 受控变更 |
| **P-11**<br/>SSH 无法连接 | `ssh pi@<IP>` 超时，或 `Connection refused` / `Permission denied (publickey)` | IP 变更（DHCP 租约/静态 IP 失效）→ 禁密码后未导入 key → ufw 误拦 22 → sshd 未启动/配置错误 | PC 端 `ping <IP>`、`nmap -sT -p22,5000 <IP>`；Pi 本地 `sudo systemctl status ssh`；`sudo ufw status`；`sudo sshd -t` | 恢复 IP 或串口登录处置；key 登录失败时临时保留密码通道排查（完即恢复 `PasswordAuthentication no`）；`sudo ufw allow 22/tcp`；`sudo systemctl reload ssh` | 改 SSH 配置时保留现有会话、先开新终端验证 key 登录成功再关闭旧会话（见 [10.1](#101-ssh-密钥登录加固)） |

---

## 10. 安全加固、备份恢复与配置清单

### 10.1 SSH 密钥登录加固与密码禁用

```bash
# PC 端生成密钥并分发
ssh-keygen -t ed25519 -C "gimbal-ops@$(hostname)"
ssh-copy-id -i ~/.ssh/id_ed25519.pub pi@<树莓派IP>

# Pi 端关闭密码登录与 root 直登
sudo sed -i 's/^#\?PasswordAuthentication.*/PasswordAuthentication no/' /etc/ssh/sshd_config
sudo sed -i 's/^#\?PermitRootLogin.*/PermitRootLogin no/' /etc/ssh/sshd_config
sudo sshd -t && sudo systemctl reload ssh

# 验证(务必先保留当前会话, 新开终端确认 key 可用后再关闭旧会话)
ssh -i ~/.ssh/id_ed25519 pi@<树莓派IP>
```

依据 NIST SP 800-123 最小暴露面原则：关闭密码认证可显著降低暴力破解面；批量设备可加装 `fail2ban`（可选加固）。

### 10.2 防火墙端口放行与串口用户组权限

```bash
sudo apt install -y ufw
sudo ufw default deny incoming
sudo ufw default allow outgoing
sudo ufw allow 22/tcp comment 'SSH'
sudo ufw allow 5000/tcp comment 'MJPEG stream'
sudo ufw enable
sudo ufw status verbose

# 串口设备组权限（/dev/ttyAMA0 属 root:dialout）
sudo usermod -aG dialout pi
ls -l /dev/serial0 /dev/ttyAMA0    # 验收: 属组 dialout, pi 在该组内
```

注意：CAN 为链路层非 IP 流量，ufw 不做过滤，CAN 访问控制依赖物理接线与 socket 权限；Web 端口 5000 为 Flask 开发服务器，禁止暴露公网。

### 10.3 关键配置文件备份与一键恢复脚本

**备份脚本**（建议每日 cron，输出归档包与 SHA256 校验值）：

```bash
#!/usr/bin/env bash
# gimbal-backup.sh —— 运维配置备份
set -euo pipefail
OUT=/home/pi/backups/gimbal-$(date +%Y%m%d-%H%M%S).tar.gz
mkdir -p "$(dirname "$OUT")"
tar czf "$OUT" \
  /boot/firmware/config.txt \
  /etc/systemd/system/gimbal-tracker.service \
  /etc/network/interfaces.d/can0 \
  /etc/ssh/sshd_config \
  /etc/ufw/user.rules \
  /etc/systemd/journald.conf \
  /etc/apt/sources.list /etc/apt/sources.list.d/raspi.list \
  "/home/pi/gimbal/2、软件代码/project"
sha256sum "$OUT" > "$OUT.sha256"
echo "备份完成: $OUT"
```

**一键恢复思路（黄金镜像 + 配置包）**：① 从黄金镜像烧录新 SD 卡；② 恢复配置包 `tar xzf <backup>.tar.gz -C /`；③ 重装 pip 依赖（[4.1](#41-apt-系统依赖安装)）；④ 重新部署模型并校验（[4.3](#43-onnx-模型部署与完整性校验)）；⑤ 执行第 3 章验收判据 + [5.4](#54-补丁验证步骤) + [5.5](#55-全链路回归验证清单) 后上线。恢复演练每季度一次并记录 MTTR。

### 10.4 运维配置项 (OP-CI) 跟踪清单

| 编号 | 配置项 | 位置 | 变更影响 | 恢复方式 |
| :---: | :--- | :--- | :--- | :--- |
| OP-CI-01 | 总线设备树配置 | `/boot/firmware/config.txt` | SPI/UART/CSI/中断；错误将导致 POST 硬失败 | 从备份包恢复后 reboot |
| OP-CI-02 | SocketCAN 自启 | `/etc/network/interfaces.d/can0` | can0 波特率与队列 | 恢复文件 + 重拉服务 |
| OP-CI-03 | 源码工程 | `2、软件代码/project/` | 控制逻辑与补丁状态 | 从备份包或版本库恢复 |
| OP-CI-04 | 模型文件 | `/home/jr/models/*.onnx` | 检测性能与 POST | 重下源 + MD5 比对 |
| OP-CI-05 | 服务单元 | `/etc/systemd/system/gimbal-tracker.service` | 守护/看门狗/资源限额 | 恢复 + `daemon-reload` |
| OP-CI-06 | SSH 加固 | `/etc/ssh/sshd_config` | 远程访问控制 | 恢复 + `sshd -t` + reload |
| OP-CI-07 | 防火墙规则 | `/etc/ufw/user.rules` | 22/5000 暴露面 | 恢复 + `ufw reload` |
| OP-CI-08 | journald 策略 | `/etc/systemd/journald.conf` | 日志留存与磁盘寿命 | 恢复 + 重启 journald |
| OP-CI-09 | 软件源 | `sources.list` / `raspi.list` / pip 配置 | 依赖安装来源 | 恢复 + `apt update` |
| OP-CI-10 | 备份与恢复编排 | `gimbal-backup.sh` + 黄金镜像 | 灾难恢复能力 | 文档与介质双归档 |

配置管理纪律：任何 OP-CI 变更须留痕（谁/何时/为何/如何回滚），变更后必须重跑第 3 章验收判据与 [5.5](#55-全链路回归验证清单)；配置项与代码同库受控，严禁在线直接修改运行中设备而不留备份。

---

## 附录 常用缩略语表

| 缩略语 | 全称与说明 |
| :--- | :--- |
| POST | Power-On Self Test，上电自检 |
| SRE | Site Reliability Engineering，站点可靠性工程 |
| SLA / SLO | 服务等级协议 / 服务等级目标 |
| MTBF / MTTR | 平均故障间隔时间 / 平均修复时间 |
| FMEA / FMECA | 失效模式与影响分析 / 失效模式、影响与危害性分析 |
| CI / CD | 持续集成 / 持续部署 |
| CVSS | 通用漏洞评分系统（3.1 版量表） |
| CAN | Controller Area Network，控制器局域网总线 |
| SocketCAN | Linux 内核 CAN 协议栈与网络接口抽象 |
| TEC / REC | CAN 发送 / 接收错误计数器 |
| BUS-OFF | CAN 总线关闭状态（TEC ≥ 256，节点离线） |
| ACK | CAN 总线应答位（无 ACK 即无节点成功接收） |
| CSI / SPI / UART / GPIO | 摄像头 MIPI 接口 / 串行外设接口 / 异步串口 / 通用输入输出 |
| PL011 | 树莓派主硬件 UART 控制器（映射为 `/dev/serial0`） |
| ONNX | 开放神经网络交换格式（YuNet 权重格式） |
| MJPEG | 动态 JPEG 视频流（Flask 推流封装） |
| PEP 668 | Python 外部管理环境标记（`--break-system-packages` 的原因） |
| SOP | 标准作业程序 |
| SSH / UFW | 安全外壳协议 / 轻量防火墙 |
| MD5 | 消息摘要算法 5（模型完整性校验） |
| OOM | Out Of Memory，内存耗尽（内核 OOM Killer 击杀进程） |
| XT30 | 大电流航模插头（24V 母线接口） |

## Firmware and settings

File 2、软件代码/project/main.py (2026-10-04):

#!/usr/bin/env python3
import time
import cv2

from camera_yunet import YuNetCamera
from tfmini_uart import TFminiReader
from gimbal_can import GimbalCAN
from mjpeg_stream import MJPEGStreamer


STREAM_W = 640
STREAM_H = 480

CENTER_X = STREAM_W // 2
CENTER_Y = STREAM_H // 2

YAW_DIRECTION = -1
PITCH_DIRECTION = 1

YAW_GAIN = 0.003
PITCH_GAIN = 0.003

MAX_YAW_SPEED = 100.0
MAX_PITCH_SPEED = 100.0

MIN_YAW_SPEED = 0.02
MIN_PITCH_SPEED = 0.02

DEADZONE_X = 15
DEADZONE_Y = 15

CONTROL_PERIOD = 0.02


def clamp(x, lo, hi):
    return max(lo, min(x, hi))


def calc_speed(error, gain, min_speed, max_speed, deadzone, direction=1):
    if abs(error) <= deadzone:
        return 0.0

    vel = abs(error) * gain
    vel = clamp(vel, min_speed, max_speed)

    if error < 0:
        vel = -vel

    return vel * direction


def draw_overlay(frame, face, distance):
    h, w = frame.shape[:2]
    cx0, cy0 = w // 2, h // 2

    cross_color = (0, 0, 255)

    if face is not None:
        x = face["x"]
        y = face["y"]
        fw = face["w"]
        fh = face["h"]

        face_cx = face["cx"]
        face_cy = face["cy"]

        err_x = face_cx - cx0
        err_y = face_cy - cy0

        if x <= cx0 <= x + fw and y <= cy0 <= y + fh:
            cross_color = (0, 255, 0)

        cv2.rectangle(frame, (x, y), (x + fw, y + fh), (0, 255, 0), 2)

        cv2.putText(frame, f"faces={face['count']}", (10, 25),
                    cv2.FONT_HERSHEY_SIMPLEX, 0.6, (255, 255, 255), 2)

        cv2.putText(frame, f"err_x={err_x}, err_y={err_y}", (10, 50),
                    cv2.FONT_HERSHEY_SIMPLEX, 0.6, (255, 255, 255), 2)
    else:
        cv2.putText(frame, "No face", (10, 25),
                    cv2.FONT_HERSHEY_SIMPLEX, 0.6, (255, 255, 255), 2)

    cv2.line(frame, (cx0 - 20, cy0), (cx0 + 20, cy0), cross_color, 2)
    cv2.line(frame, (cx0, cy0 - 20), (cx0, cy0 + 20), cross_color, 2)

    if distance is None:
        distance_text = "Distance: -- cm"
    else:
        distance_text = f"Distance: {distance} cm"

    text_size, _ = cv2.getTextSize(distance_text, cv2.FONT_HERSHEY_SIMPLEX, 0.6, 2)
    text_x = w - text_size[0] - 10

    cv2.putText(frame, distance_text, (text_x, 30),
                cv2.FONT_HERSHEY_SIMPLEX, 0.6, (255, 255, 255), 2)

    return frame


def main():
    camera = YuNetCamera()
    lidar = TFminiReader()
    streamer = MJPEGStreamer()
    gimbal = GimbalCAN()

    lidar.start()
    streamer.start()

    last_control_time = time.time()

    print("Starting speed-mode face tracking...")
    print("Browser: http://<raspberrypi_ip>:5000")
    print("Press Ctrl+C to stop.")

    try:
        gimbal.enable()
        time.sleep(0.5)
        gimbal.stop()

        while True:
            frame = camera.read()
            face = camera.detect_largest_face(frame)
            distance = lidar.get_distance()

            now = time.time()

            if now - last_control_time >= CONTROL_PERIOD:
                if face is not None:
                    err_x = face["cx"] - CENTER_X
                    err_y = face["cy"] - CENTER_Y

                    yaw_vel = calc_speed(
                        err_x,
                        YAW_GAIN,
                        MIN_YAW_SPEED,
                        MAX_YAW_SPEED,
                        DEADZONE_X,
                        YAW_DIRECTION
                    )

                    pitch_vel = calc_speed(
                        err_y,
                        PITCH_GAIN,
                        MIN_PITCH_SPEED,
                        MAX_PITCH_SPEED,
                        DEADZONE_Y,
                        PITCH_DIRECTION
                    )

                    gimbal.send_speed(yaw_vel, pitch_vel)

                else:
                    gimbal.stop()

                last_control_time = now

            display_frame = draw_overlay(frame, face, distance)
            streamer.update_frame(display_frame)

    except KeyboardInterrupt:
        print("\nStopping...")

    finally:
        try:
            gimbal.stop()
            time.sleep(0.2)
            gimbal.disable()
            gimbal.close()
            lidar.stop()
        except Exception as e:
            print(f"Shutdown error: {e}")

        print("Exit.")


if __name__ == "__main__":
    main()

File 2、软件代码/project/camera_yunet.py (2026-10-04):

from picamera2 import Picamera2
import cv2
import time
import os


class YuNetCamera:
    def __init__(
        self,
        model_path="/home/jr/models/face_detection_yunet_2023mar.onnx",
        capture_size=(1640, 1232),
        # capture_size=(2304, 1296),        
        stream_size=(640, 480),
    ):
        if not os.path.exists(model_path):
            raise FileNotFoundError(model_path)

        self.capture_size = capture_size
        self.stream_size = stream_size

        self.picam2 = Picamera2()
        config = self.picam2.create_video_configuration(
            main={"size": self.capture_size, "format": "RGB888"}
        )
        self.picam2.configure(config)
        self.picam2.start()

        self.picam2.set_controls({
            "AeEnable": True,
            "AwbEnable": True,
            "FrameDurationLimits": (20000, 20000)
        })

        time.sleep(1)

        self.detector = cv2.FaceDetectorYN.create(
            model_path,
            "",
            self.stream_size,
            score_threshold=0.6,
            nms_threshold=0.3,
            top_k=5000,
        )

    def read(self):
        frame = self.picam2.capture_array()
        frame = cv2.resize(frame, self.stream_size)

        # Picamera2 输出 RGB，OpenCV/YuNet 使用 BGR
        # frame = cv2.cvtColor(frame, cv2.COLOR_RGB2BGR)

        return frame

    def detect_faces(self, frame):
        self.detector.setInputSize(self.stream_size)
        _, faces = self.detector.detect(frame)

        if faces is None:
            return [], None

        result = []

        for f in faces:
            x, y, w, h = f[:4].astype(int)

            result.append({
                "x": x,
                "y": y,
                "w": w,
                "h": h,
                "cx": x + w // 2,
                "cy": y + h // 2,
                "area": w * h,
            })

        # 默认选择面积最大的人脸作为跟踪目标
        selected_face = max(result, key=lambda face: face["area"])

        return result, selected_face

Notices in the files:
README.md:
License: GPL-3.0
